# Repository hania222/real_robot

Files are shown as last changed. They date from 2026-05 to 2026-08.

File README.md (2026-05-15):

# Real Robot: Setup & Commissioning Guide
## Table of Contents

1. [SSH Connection, Repo Clone & Dependency Install](#1-ssh-connection-repo-clone--dependency-install)
2. [udev Fixed Device Names for RPLidar & ESP32](#2-udev-fixed-device-names-for-rplidar--esp32)
3. [PID Tuning & Physical Calibration](#3-pid-tuning--physical-calibration)
4. [SLAM Toolbox — Building the Map](#4-slam-toolbox--building-the-map)
5. [Nav2 — Autonomous Navigation](#5-nav2--autonomous-navigation)
---

## 1. SSH Connection, Repo Clone & Dependency Install

### 1.1 Find the Pi 5's IP address

Run this on the Pi (connected to a monitor temporarily, or check the router's DHCP table):

```bash
hostname -I
# returns something like 192.168.1.42 — note this down
```
---

### 1.2 SSH from the Windows laptop into Pi 5
Both devices must be on the same network (same Wi-Fi or router).

```powershell
# In Windows PowerShell
ssh hania@192.168.1.42
# Replace the IP with the one from step 1.1
# Default Pi username is 'hania' — change if different
# Accept the fingerprint prompt , enter ur Pi password
```

>  **Tip:** To avoid typing the password every time, set up SSH key auth: run `ssh-keygen` on Windows, then `ssh-copy-id hania@<IP>`.

---

### 1.3 Create workspace and clone the repo

All commands run on Pi 5 over SSH.

```bash
# Create workspace
mkdir -p ~/robot_ws/src
cd ~/robot_ws/src

# Clone the repo
git clone https://github.com/hania222/real_robot.git

# Verify it cloned
ls real_robot/
```

---

### 1.4 Run install_deps.sh to install all dependencies

Installs ROS 2 packages, Nav2, slam_toolbox, robot_localization, and more.

```bash
cd ~/robot_ws/src/real_robot
chmod +x install_deps.sh
./install_deps.sh
# This will sudo apt install everything — takes a few minutes
```

> **micro-ROS agent is NOT available via apt, it must be built from source.** 

micro-ROS agent must be built from source, it's not available via apt. Build it once here, then run it manually in its own terminal to verify the ESP32 is connected
and publishing before launching bringup. It's commented out in bringup.launch.py intentionally, uncomment it only after confirming everything works end-to-end.:

```bash
cd ~
git clone https://github.com/micro-ROS/micro_ros_setup.git src/micro_ros_setup
cd ~/robot_ws
colcon build --packages-select micro_ros_setup
source install/setup.bash
ros2 run micro_ros_setup create_agent_ws.sh
ros2 run micro_ros_setup build_agent.sh
source install/setup.bash
```

---

### 1.5 Build the workspace

```bash
cd ~/robot_ws
colcon build --symlink-install
source install/setup.bash

# Add to .bashrc so it auto-sources on every SSH login
echo "source ~/robot_ws/install/setup.bash" >> ~/.bashrc
source ~/.bashrc
```
>note: we will use our built .bashrc directly 
---

## 2. udev Fixed Device Names for RPLidar & ESP32

> **Why this matters:** Linux assigns `/dev/ttyUSB0` and `/dev/ttyUSB1` randomly on boot. without udev rules the launch files will connect to the wrong device. These rules pin names by USB vendor/product ID so the lidar is always `/dev/rplidar` and the ESP32 is always `/dev/esp32`.

### 2.1 Find the USB vendor and product IDs

```bash
# Plug only the RPLidar in first
lsusb
# Look for "Silicon Labs CP210x" or "Prolific" — note idVendor:idProduct
# Example: Bus 001 Device 003: ID 10c4:ea60 Silicon Labs CP210x

# Now also plug in the ESP32
lsusb
# ESP32 usually shows up as Silicon Labs CP2102 or CH340
# Note the different idVendor:idProduct for each

# Also check the serial number to distinguish two Silicon Labs devices
udevadm info /dev/ttyUSB0 | grep -E "ID_VENDOR_ID|ID_MODEL_ID|ID_SERIAL_SHORT"
udevadm info /dev/ttyUSB1 | grep -E "ID_VENDOR_ID|ID_MODEL_ID|ID_SERIAL_SHORT"
```

---

### 2.2 Create the udev rules file

```bash
sudo nano /etc/udev/rules.d/99-robot.rules
```

Paste this: replace values with what we got:

```
# RPLidar A1 (Silicon Labs CP2102 — adjust ATTRS if needed)
SUBSYSTEM=="tty", ATTRS{idVendor}=="10c4", ATTRS{idProduct}=="ea60", \
  ATTRS{serial}=="YOUR_LIDAR_SERIAL", \
  SYMLINK+="rplidar", MODE="0666"

# ESP32 (CP2102 or CH340 — adjust idVendor/idProduct)
SUBSYSTEM=="tty", ATTRS{idVendor}=="10c4", ATTRS{idProduct}=="ea60", \
  ATTRS{serial}=="YOUR_ESP32_SERIAL", \
  SYMLINK+="esp32", MODE="0666"
```

>  If both devices share the same VID:PID (both are CP2102), use the serial number field to tell them apart — that's why u ran the `ID_SERIAL_SHORT` check above.

---

### 2.3 Reload udev and verify symlinks

Unplug and replug both USB devices after reloading.

```bash
sudo udevadm control --reload-rules
sudo udevadm trigger

# Unplug both, replug both, then verify:
ls -la /dev/rplidar /dev/esp32
# Both should appear as symlinks → /dev/ttyUSBx
```

> Update `bringup.launch.py`'s `serial_port` to `/dev/rplidar` now that the symlink is stable.

---

## 3. PID Tuning & Physical Calibration

> **Before starting:** launch bringup first (`ros2 launch real_bringup bringup.launch.py`), then the joystick or step_tester in a separate terminal. PlotJuggler subscribes to `/pid_debug` to visualise target vs actual speed in real time.

---

### Step 1 — PID Tuning (KP first, then KI, then KD)

Use `step_tester.py` in linear mode + PlotJuggler `/pid_debug`.

```bash
# Terminal 1 — bringup
ros2 launch real_bringup bringup.launch.py

# Terminal 2 — step tester (3 s ON / 3 s OFF cycle)
python3 step_tester.py linear

# Terminal 3 — live publish gains without reflashing
ros2 topic pub /pid_gains std_msgs/msg/String \
  "data: 'kp_l:80.0 ki_l:5.0 kd_l:1.0 kp_r:80.0 ki_r:5.0 kd_r:1.0'"
```

**Tuning order:**
1. Set KI=0 KD=0. Raise KP until actual speed tracks target without oscillation in PlotJuggler.
2. Slowly raise KI (try 1 → 2 → 5) until the steady-state offset closes. Halve if oscillation appears.
3. Add KD (try 0.5 → 1 → 2) only if velocity still oscillates with good KP + KI. Usually not needed.

> When satisfied, write the final KP/KI/KD values back into `config.h` and reflash the ESP32 — the `/pid_gains` topic is runtime-only and resets on reboot.

---

### Step 2 — Verify wheel radius (tape measure)

Confirm `WHEEL_RADIUS = 0.065 m` in `config.h` matches the physical wheel.

1. Mark a straight line on the floor. Place the robot with the wheel edge on the line.
2. Command a known distance — e.g. run `step_tester.py linear` for exactly 3 s at 0.3 m/s → expected travel = 0.9 m.
3. Measure the actual distance traveled with a tape measure.
4. If actual ≠ expected: `new_radius = (actual / expected) × 0.065`. Update `WHEEL_RADIUS` in `config.h` and reflash.

```bash
# Check /odom reports expected distance too
ros2 topic echo /odom --once
# pose.pose.position.x should match tape measure
```

---

### Step 3 — Verify wheel base (360° spin test)

Confirm `WHEEL_BASE = 0.642 m` matches physical axle separation.

1. Put a marker (tape) under the robot centre. Run `step_tester.py angular` until the robot completes exactly one full 360° spin.
2. If the robot overshoots: increase `WHEEL_BASE`. If it undershoots: decrease it.
3. Formula: `new_base = (actual_degrees / 360) × 0.642`
4. Update `config.h` and also `ekf.yaml` if derived from the URDF joints (URDF has 0.642 m: left_drive y=0.321 + right_drive y=0.321).

```bash
# Monitor yaw angle from odometry during spin
ros2 topic echo /odom | grep -A2 "orientation"
```

---

### Step 4 — Minimum reliable speed (`MIN_LINEAR`)

Find the slowest speed at which both wheels move without stalling.

1. Command progressively slower speeds via `/pid_gains` and `step_tester.py`.
2. In PlotJuggler watch `actual_v_left` and `actual_v_right` — the minimum speed where both wheels consistently move is your `MIN_LINEAR`.
3. Update `MIN_LINEAR` in `joystick_ws_node.py` and `MIN_WHEEL_SPEED` in `config.h` to match.
4. Also set `min_vel_x` in `nav2_params.yaml` to the same number.

Current default: `MIN_LINEAR = 0.10 m/s`

---

### Step 5 — Acceleration / deceleration profile

Tune `MAX_ACCEL_PER_TICK` so the robot starts smoothly without jerking.

1. Run `step_tester.py linear` and watch the *slewed target* line (`debug_data[0]`) in PlotJuggler — it should ramp smoothly.
2. If the gearbox jolts on start: lower `MAX_ACCEL_PER_TICK` from `0.05` to `0.03` in `config.h`.
3. If the robot reaches cruising speed too slowly: raise to `0.1` or `0.2`.

Current default: `0.05 m/s per 50 ms tick = 1.0 m/s² acceleration`

```
# PlotJuggler topics to watch:
# /pid_debug → [0] slewed_left, [1] actual_left, [3] pwm_left
#               [4] slewed_right, [5] actual_right, [7] pwm_right
```

---

### Step 6 — Verify robot footprint dimensions

Tape measure the physical robot for the Nav2 footprint polygon (outermost points including caster wheels).

```yaml
# In nav2_params.yaml, update the footprint polygon:
footprint: [[-0.15, 0.32], [0.50, 0.32], [0.50, -0.32], [-0.15, -0.32]]
# Adjust X,Y values to match tape measure results (in metres)
# X = front/back from robot centre, Y = left/right from centre
```

>  From the URDF: chassis extends roughly +0.35 m to the front, −0.15 m to the rear, ±0.32 m sideways — verify against the real robot.

---

## 4. SLAM Toolbox — Building the Map

>  **TwistStamped vs Twist:** During SLAM, the joystick node publishes `TwistStamped` on `/cmd_vel_stamped` directly to the ESP32. The `twist_to_twiststamped.py` bridge converts `/cmd_vel → /cmd_vel_stamped` if using tools that publish plain Twist (like `teleop_twist_keyboard`). Make sure the bridge is running during SLAM manual driving.

### 4.1 Start bringup

```bash
# Terminal 1 (always start bringup first)
ros2 launch real_bringup bringup.launch.py

# Wait ~3 seconds, then verify TF tree:
ros2 run tf2_tools view_frames
# Should show: odom → CHASSIS → LIDAR and imu_link
# If odom→CHASSIS is missing, EKF hasn't started yet — wait and retry
```

> Uncomment the `micro_ros_agent` block in `bringup.launch.py` before running on the real robot

---

### 4.2 Launch SLAM toolbox

```bash
# Terminal 2
ros2 launch real_bringup slam.launch.py
# slam_params.yaml must set odom_frame: odom and base_frame: CHASSIS
# use_sim_time: false
```

---

### 4.3 Drive the robot to build the map

```bash
#  WebSocket joystick (Terminal 3 on Pi)
ros2 launch real_bringup joystick.launch.py
# Open the joystick HTML page in browser → connect to ws://<PI_IP>:8765
```

Drive slowly and cover all areas. Watch RViz to confirm the map is building cleanly without jumps.

---

### 4.4 View the map in RViz (Windows laptop)

Both machines must be on the same network and share the same `ROS_DOMAIN_ID`.

```powershell
# On Windows (ROS 2 must be installed) — PowerShell
set ROS_DOMAIN_ID=0
rviz2
# Add displays: Map (/map), LaserScan (/scan), TF, RobotModel
```

> Alternatively, run RViz on the Pi over SSH with X forwarding: `ssh -X hania@<PI_IP>` then `rviz2` — but this is slow over Wi-Fi.

---

### 4.5 Save the map

```bash
# While SLAM is still running — save the map
ros2 run nav2_map_server map_saver_cli \
  -f ~/robot_ws/src/real_robot/real_bringup/maps/real_map
# Creates real_map.pgm (image) and real_map.yaml (metadata)
# navigation.launch.py already points to real_map.yaml by default
```

---

## 5. Nav2 — Autonomous Navigation

>  **Twist vs TwistStamped for Nav2:** Nav2's `controller_server` publishes plain `Twist` on `/cmd_vel` by default. The ESP32 subscribes to `TwistStamped` on `/cmd_vel_stamped`. we must either:
> - **(a)** Run the `twist_to_twiststamped.py` bridge alongside Nav2, or
> - **(b)** Configure Nav2 to publish TwistStamped directly: set `enable_stamped_cmd_vel: true` in `nav2_params.yaml` (available in Nav2 Jazzy/Iron+).
>
> Option (b) is cleaner — no extra node needed.

### 5.1 Configure nav2_params.yaml

```yaml
# Under controller_server:
enable_stamped_cmd_vel: true   # publishes TwistStamped on /cmd_vel_stamped

# Under local_costmap and global_costmap:
robot_base_frame: CHASSIS       # must match EKF base_link_frame

# Under DWB or MPPI controller:
min_vel_x: 0.10                 # match MIN_LINEAR from step 3.4
max_vel_x: 0.70                 # match MAX_LINEAR (70% of rated 1.2 m/s)
max_vel_theta: 1.5              # match MAX_ANGULAR

# Footprint (from step 3.6 tape measure)
footprint: "[[-0.15, 0.32], [0.50, 0.32], [0.50, -0.32], [-0.15, -0.32]]"
```

---

### 5.2 Configure amcl_params.yaml

```yaml
base_frame_id: CHASSIS
odom_frame_id: odom
scan_topic:    /scan
laser_model_type: likelihood_field
use_sim_time: false

# Particle filter sizing (start broad, tighten once map is good)
min_particles: 500
max_particles: 2000
```

---

### 5.3 Launch bringup + navigation

```bash
# Terminal 1
ros2 launch real_bringup bringup.launch.py

# Terminal 2 — waits 5 s automatically via TimerAction
ros2 launch real_bringup navigation.launch.py

# Optionally pass a different map
ros2 launch real_bringup navigation.launch.py \
  map:=/path/to/another_map.yaml
```

> The lifecycle manager is delayed 5 s in `navigation.launch.py` to wait for bringup's TF tree to be available. If Nav2 reports "map→odom TF not available", bringup hasn't finished — increase the delay or wait before launching navigation.

---

### 5.4 Set initial pose in RViz and test navigation

1. In RViz, click **2D Pose Estimate** and click on the map at the robot's approximate location, dragging to set orientation.
2. Watch the particle cloud (AMCL) in RViz converge around the robot as it moves.
3. Click **Nav2 Goal** (or **2D Nav Goal**) and click a destination on the map.
4. Monitor `/cmd_vel_stamped` to confirm Nav2 is sending commands to the ESP32.

```bash
# Confirm Nav2 is sending velocity commands
ros2 topic echo /cmd_vel_stamped

# Check AMCL particle convergence
ros2 topic echo /amcl_pose
```

---

### 5.5 Troubleshooting

| Symptom | Likely cause | Fix |
|---|---|---|
| Robot doesn't move at all | micro_ros_agent not running or ESP32 not connected | Uncomment `micro_ros_agent` in `bringup.launch.py`, check `/dev/esp32` symlink |
| TF tree missing odom→CHASSIS | EKF not publishing — no `/odom` or `/imu/data` from ESP32 | Check `ros2 topic hz /odom` and `ros2 topic hz /imu/data` |
| SLAM map has jumps/tears | Driving too fast, or odometry error accumulation | Drive slower, recheck wheel radius and wheel base calibration |
| Nav2 not sending /cmd_vel_stamped | `enable_stamped_cmd_vel` not set; bridge not running | Add `enable_stamped_cmd_vel: true` to `nav2_params.yaml` or run `twist_to_twiststamped.py` bridge |
| AMCL particles scattered all over | Bad initial pose estimate or map doesn't match environment | Re-set 2D Pose Estimate in RViz; remap if environment changed significantly |
| Robot hits obstacles in Nav2 | Footprint too small in `nav2_params.yaml` | Update footprint polygon from tape measure (step 3.6) with extra margin |

---

## Quick Reference

| Item | Value |
|---|---|
| Workspace | `~/robot_ws` |
| Package | `real_bringup` |
| Map save path | `real_bringup/maps/real_map` |
| Lidar device | `/dev/rplidar` |
| ESP32 device | `/dev/esp32` |
| ROS 2 distro | Jazzy |
| URDF base frame | `CHASSIS` |
| Odom frame | `odom` |
| Wheel radius | `0.065 m` |
| Wheel base | `0.642 m` |
| Min linear speed | `0.10 m/s` |

---

**Repo:** [github.com/hania222/real_robot](https://github.com/hania222/real_robot) · Workspace: `~/robot_ws` · ROS 2 Jazzy · micro-ROS on ESP32

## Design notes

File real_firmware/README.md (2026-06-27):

# Carriage Subsystem — Wiring Reference

## Active-LOW wiring (negative pins → ESP32 GPIOs, positive pins → 3.3V)
ESP32 is 3.3V logic — add a 1kΩ resistor in series on each signal line (PUL, DIR, ENA).

| From | To | Note |
|---|---|---|
| ESP32 GPIO 18 | 1kΩ resistor → TB6600 Rot PUL− | Rotation step pulse |
| ESP32 GPIO 19 | 1kΩ resistor → TB6600 Rot DIR− | Rotation direction |
| ESP32 GPIO 21 | 1kΩ resistor → TB6600 Rot ENA− | Rotation enable (LOW = enabled) |
| ESP32 GPIO 22 | 1kΩ resistor → TB6600 Ext1 PUL− | Extension step pulse (both drivers) |
| ESP32 GPIO 22 | 1kΩ resistor → TB6600 Ext2 PUL− | Same GPIO wired to both |
| ESP32 GPIO 23 | 1kΩ resistor → TB6600 Ext1 DIR− | Extension direction (both drivers) |
| ESP32 GPIO 23 | 1kΩ resistor → TB6600 Ext2 DIR− | Same GPIO wired to both |
| ESP32 GPIO 25 | 1kΩ resistor → TB6600 Ext1 ENA− | Extension driver 1 enable |
| ESP32 GPIO 26 | 1kΩ resistor → TB6600 Ext2 ENA− | Extension driver 2 enable |
| ESP32 3.3V | TB6600 Rot PUL+ |  |
| ESP32 3.3V | TB6600 Rot DIR+ | |
| ESP32 3.3V | TB6600 Rot ENA+ | |
| ESP32 3.3V | TB6600 Ext1 PUL+ | |
| ESP32 3.3V | TB6600 Ext1 DIR+ | |
| ESP32 3.3V | TB6600 Ext1 ENA+ | |
| ESP32 3.3V | TB6600 Ext2 PUL+ | |
| ESP32 3.3V | TB6600 Ext2 DIR+ | |
| ESP32 3.3V | TB6600 Ext2 ENA+ | |
| ESP32 GND | TB6600 Rot GND (signal) |  |
| ESP32 GND | TB6600 Ext1 GND (signal) | |
| ESP32 GND | TB6600 Ext2 GND (signal) | |
| ESP32 GPIO 32 | Arm home switch leg A | LOW = triggered |
| ESP32 GPIO 13 | Arm end switch leg A | |
| ESP32 GPIO 33 | Rotation home switch leg A | LOW = triggered |
| ESP32 GND | All switch leg B | |
| ESP32 GPIO 27 | Servo left signal | SG90 signal wire |
| ESP32 GPIO 14 | Servo right signal | SG90 signal wire |
| External 5V rail | Both SG90 red wire (VCC) | Do NOT power servos from ESP32 5V pin |
| External 5V GND | Both SG90 brown wire (GND) | |
| External 5V GND | ESP32 GND | Common ground between servo rail and ESP32 |
| 24V PSU positive | TB6600 Rot VCC | Motor power |
| 24V PSU positive | TB6600 Ext1 VCC | |
| 24V PSU positive | TB6600 Ext2 VCC | |
| 24V PSU negative | TB6600 Rot GND (power) | |
| 24V PSU negative | TB6600 Ext1 GND (power) | |
| 24V PSU negative | TB6600 Ext2 GND (power) | |
| 24V PSU negative | ESP32 GND | Star ground — tie all GNDs together |
| TB6600 Rot A+ | Rotation NEMA23 coil A+ | |
| TB6600 Rot A− | Rotation NEMA23 coil A− | |
| TB6600 Rot B+ | Rotation NEMA23 coil B+ | |
| TB6600 Rot B− | Rotation NEMA23 coil B− | |
| TB6600 Ext1 A+ | Extension NEMA17 motor 1 coil A+ | |
| TB6600 Ext1 A− | Extension NEMA17 motor 1 coil A− | |
| TB6600 Ext1 B+ | Extension NEMA17 motor 1 coil B+ | |
| TB6600 Ext1 B− | Extension NEMA17 motor 1 coil B− | |
| TB6600 Ext2 A+ | Extension NEMA17 motor 2 coil A+ | |
| TB6600 Ext2 A− | Extension NEMA17 motor 2 coil A− | |
| TB6600 Ext2 B+ | Extension NEMA17 motor 2 coil B+ | |
| TB6600 Ext2 B− | Extension NEMA17 motor 2 coil B− | |

Firmware: `enable_driver()` writes LOW, `disable_driver()` writes HIGH.
`DRIVER_ENABLE_LEVEL LOW`, `DRIVER_DISABLE_LEVEL HIGH` in config.

---

## Active-HIGH wiring (positive pins → ESP32 GPIOs, negative pins → GND)
Simpler for 3.3V ESP32 — no resistors needed because GND reference is solid.
The optocoupler sees the full 3.3V swing directly

| From | To | Note |
|---|---|---|
| ESP32 GPIO 18 | TB6600 Rot PUL+ | Rotation step pulse |
| ESP32 GPIO 19 | TB6600 Rot DIR+ | Rotation direction |
| ESP32 GPIO 21 | TB6600 Rot ENA+ | Rotation enable (HIGH = enabled) |
| ESP32 GPIO 22 | TB6600 Ext1 PUL+ | Extension step pulse (both drivers) |
| ESP32 GPIO 22 | TB6600 Ext2 PUL+ | Same GPIO wired to both |
| ESP32 GPIO 23 | TB6600 Ext1 DIR+ | Extension direction (both drivers) |
| ESP32 GPIO 23 | TB6600 Ext2 DIR+ | Same GPIO wired to both |
| ESP32 GPIO 25 | TB6600 Ext1 ENA+ | Extension driver 1 enable |
| ESP32 GPIO 26 | TB6600 Ext2 ENA+ | Extension driver 2 enable |
| ESP32 GND | TB6600 Rot PUL− | -ve side of optocoupler tied to GND |
| ESP32 GND | TB6600 Rot DIR− | |
| ESP32 GND | TB6600 Rot ENA− | |
| ESP32 GND | TB6600 Ext1 PUL− | |
| ESP32 GND | TB6600 Ext1 DIR− | |
| ESP32 GND | TB6600 Ext1 ENA− | |
| ESP32 GND | TB6600 Ext2 PUL− | |
| ESP32 GND | TB6600 Ext2 DIR− | |
| ESP32 GND | TB6600 Ext2 ENA− | |
| ESP32 GND | TB6600 Rot GND (signal) | Common ground |
| ESP32 GND | TB6600 Ext1 GND (signal) | |
| ESP32 GND | TB6600 Ext2 GND (signal) | |
| ESP32 GPIO 32 | Arm home switch leg A | INPUT_PULLUP, LOW = triggered |
| ESP32 GPIO 13 | Arm end switch leg A | INPUT_PULLUP, LOW = triggered  |
| ESP32 GPIO 33 | Rotation home switch leg A | INPUT_PULLUP, LOW = triggered |
| ESP32 GND | All switch leg B | |
| ESP32 GPIO 27 | Servo left signal | SG90 signal wire |
| ESP32 GPIO 14 | Servo right signal | SG90 signal wire |
| External 5V rail | Both SG90 red wire (VCC) |  |
| External 5V GND | Both SG90 brown wire (GND) | |
| External 5V GND | ESP32 GND | Common ground between servo rail and ESP32 |
| 24V PSU positive | TB6600 Rot VCC | Motor power |
| 24V PSU positive | TB6600 Ext1 VCC | |
| 24V PSU positive | TB6600 Ext2 VCC | |
| 24V PSU negative | TB6600 Rot GND (power) | |
| 24V PSU negative | TB6600 Ext1 GND (power) | |
| 24V PSU negative | TB6600 Ext2 GND (power) | |
| 24V PSU negative | ESP32 GND | all GNDs together |
| TB6600 Rot A+ | Rotation NEMA23 coil A+ | |
| TB6600 Rot A− | Rotation NEMA23 coil A− | |
| TB6600 Rot B+ | Rotation NEMA23 coil B+ | |
| TB6600 Rot B− | Rotation NEMA23 coil B− | |
| TB6600 Ext1 A+ | Extension NEMA17 motor 1 coil A+ | |
| TB6600 Ext1 A− | Extension NEMA17 motor 1 coil A− | |
| TB6600 Ext1 B+ | Extension NEMA17 motor 1 coil B+ | |
| TB6600 Ext1 B− | Extension NEMA17 motor 1 coil B− | |
| TB6600 Ext2 A+ | Extension NEMA17 motor 2 coil A+ | |
| TB6600 Ext2 A− | Extension NEMA17 motor 2 coil A− | |
| TB6600 Ext2 B+ | Extension NEMA17 motor 2 coil B+ | |
| TB6600 Ext2 B− | Extension NEMA17 motor 2 coil B− | |

Firmware: `enable_driver()` writes HIGH, `disable_driver()` writes LOW.
`DRIVER_ENABLE_LEVEL HIGH`, `DRIVER_DISABLE_LEVEL LOW` in config.

---

# Lift Subsystem — Wiring Reference
| From | To |
|---|---|
| Arduino D4 | TB6600 Driver 1 PUL− |
| Arduino D4 | TB6600 Driver 2 PUL− |
| Arduino D5 | TB6600 Driver 1 DIR− |
| Arduino D5 | TB6600 Driver 2 DIR− |
| Arduino D6 | TB6600 Driver 1 ENA− |
| Arduino D7 | TB6600 Driver 2 ENA− |
| Arduino D8 | Bottom limit switch leg A |
| Arduino D9 | Top limit switch leg A |
| Arduino 5V | TB6600 Driver 1 PUL+ |
| Arduino 5V | TB6600 Driver 1 DIR+ |
| Arduino 5V | TB6600 Driver 1 ENA+ |
| Arduino 5V | TB6600 Driver 2 PUL+ |
| Arduino 5V | TB6600 Driver 2 DIR+ |
| Arduino 5V | TB6600 Driver 2 ENA+ |
| Arduino GND | TB6600 Driver 1 GND (signal) |
| Arduino GND | TB6600 Driver 2 GND (signal) |
| Arduino GND | Bottom limit switch leg B |
| Arduino GND | Top limit switch leg B |
| Arduino GND | 24V PSU negative |
| 24V PSU positive | TB6600 Driver 1 VCC |
| 24V PSU positive | TB6600 Driver 2 VCC |
| 24V PSU negative | TB6600 Driver 1 GND (power) |
| 24V PSU negative | TB6600 Driver 2 GND (power) |
| TB6600 Driver 1 A+ | Motor 1 coil A+ |
| TB6600 Driver 1 A− | Motor 1 coil A− |
| TB6600 Driver 1 B+ | Motor 1 coil B+ |
| TB6600 Driver 1 B− | Motor 1 coil B− |
| TB6600 Driver 2 A+ | Motor 2 coil A+ |
| TB6600 Driver 2 A− | Motor 2 coil A− |
| TB6600 Driver 2 B+ | Motor 2 coil B+ |
| TB6600 Driver 2 B− | Motor 2 coil B− |

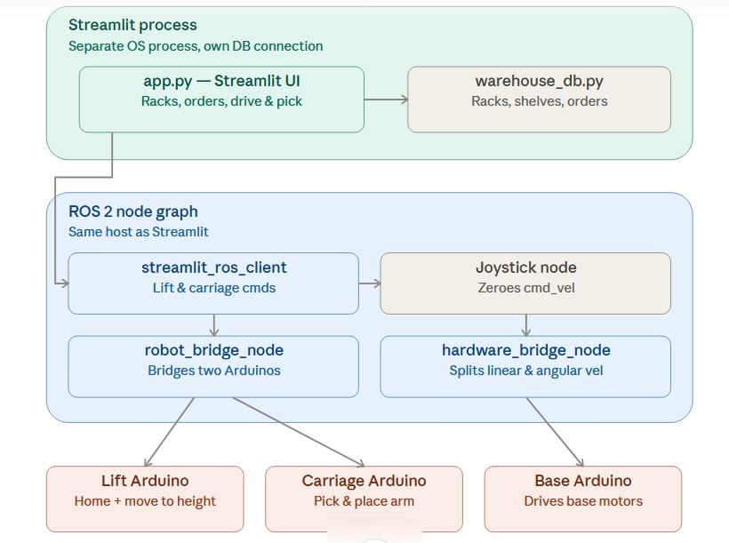
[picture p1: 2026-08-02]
management_system/sysetm_architecture.jpeg

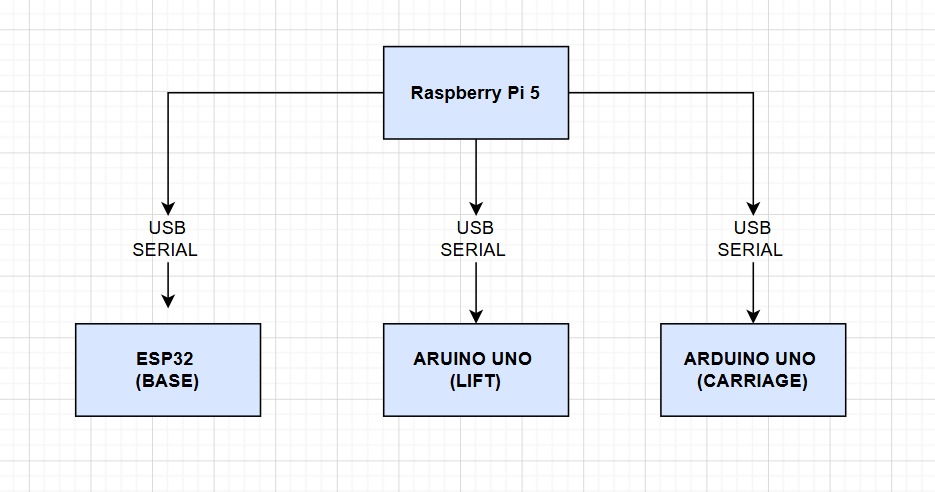
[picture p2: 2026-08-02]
management_system/system.jpeg

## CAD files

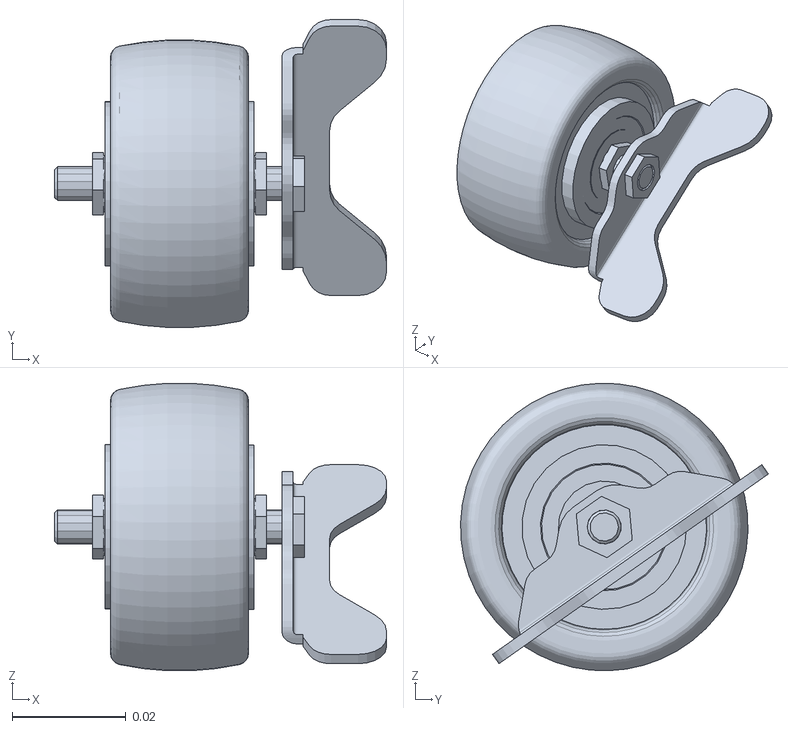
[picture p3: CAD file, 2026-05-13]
real_description/meshes/RL_swivel.STL
0.0584 x 0.0542 x 0.0506

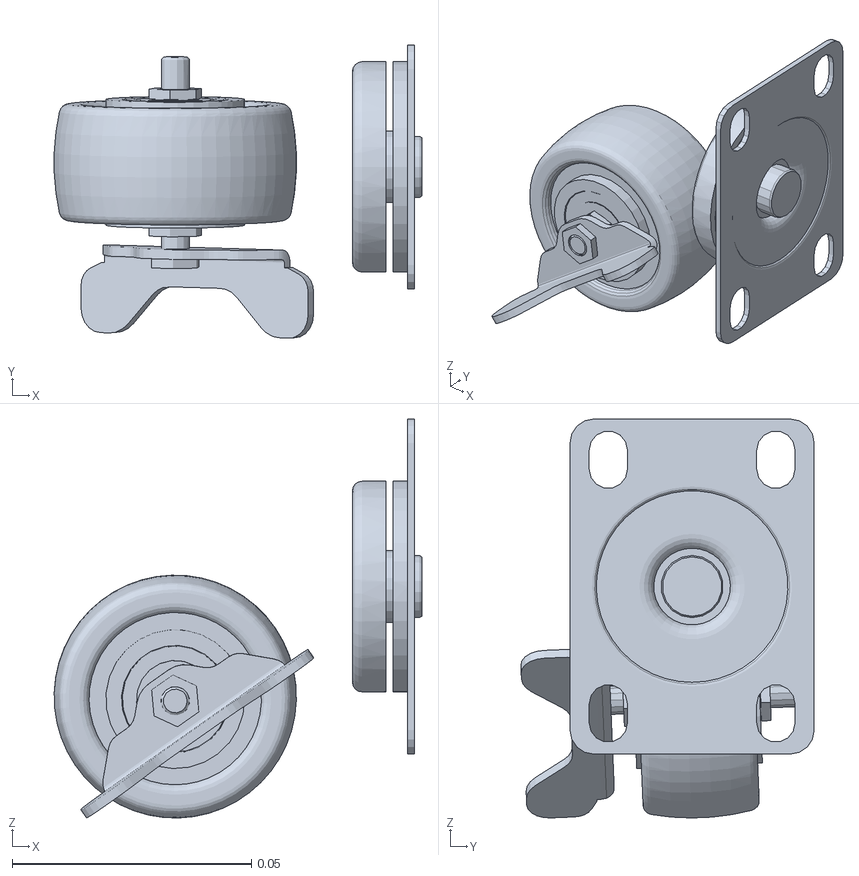
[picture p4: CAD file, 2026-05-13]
real_description/meshes/FR_swivel.STL
0.0768 x 0.0613 x 0.0833

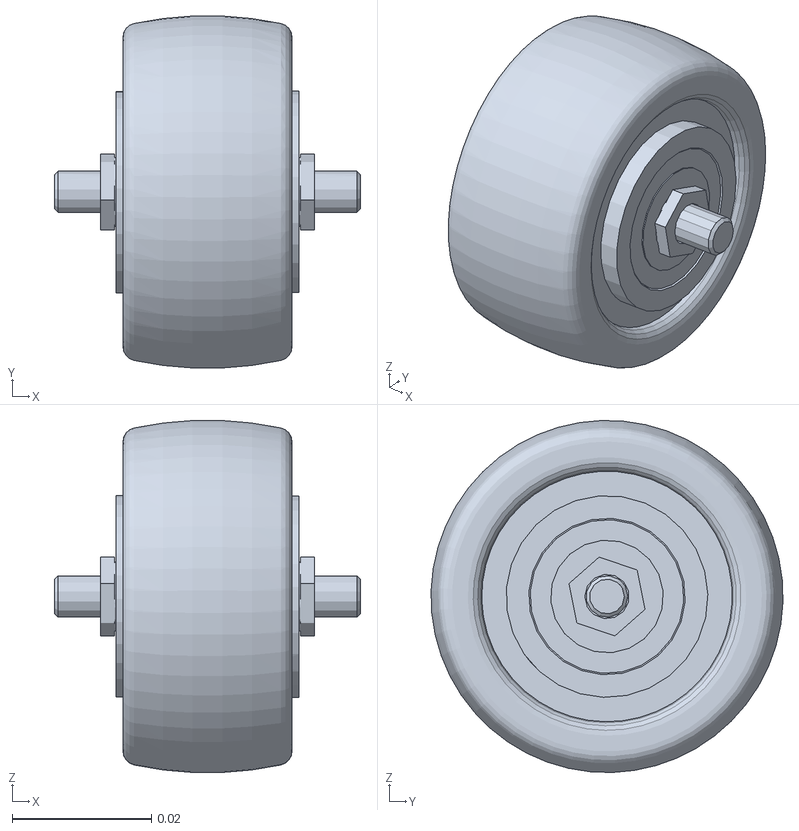
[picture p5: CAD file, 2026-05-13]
real_description/meshes/RR_roll.STL
0.044 x 0.0506 x 0.0506

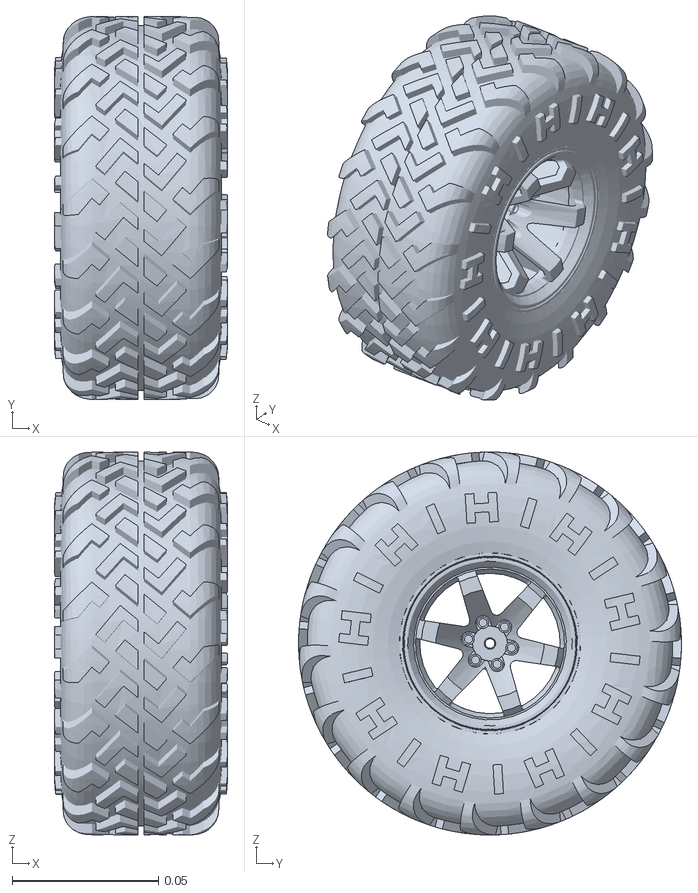
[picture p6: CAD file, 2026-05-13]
real_description/meshes/LEFT_drive.STL
0.0592 x 0.131 x 0.131

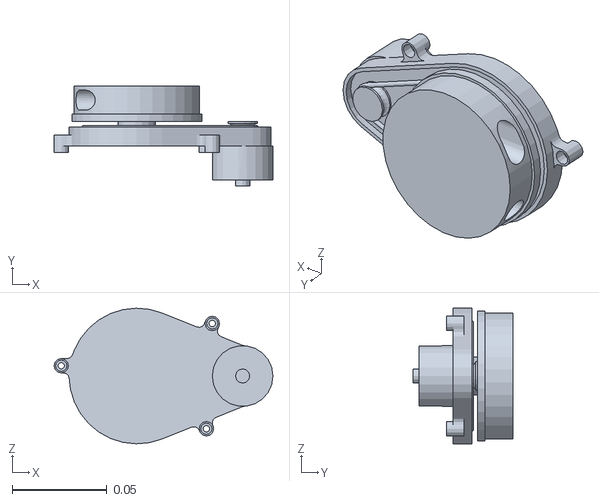
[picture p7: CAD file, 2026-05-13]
real_description/meshes/LIDAR.STL
0.115 x 0.0525 x 0.0715

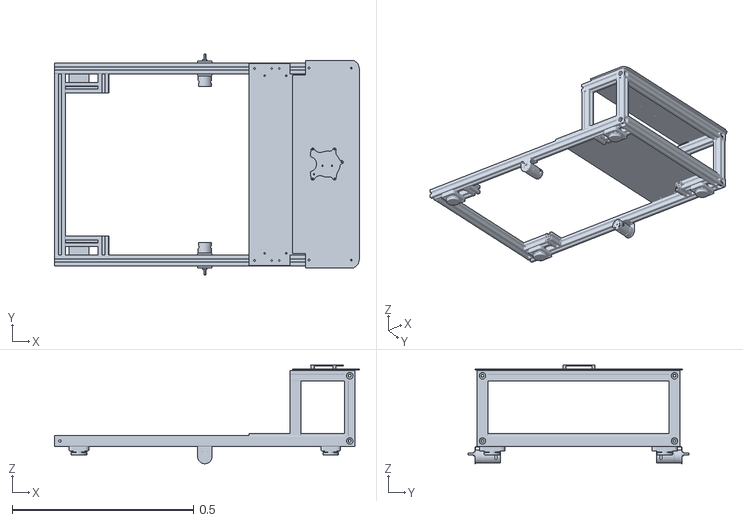
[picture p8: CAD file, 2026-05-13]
real_description/meshes/CHASSIS.STL
0.842 x 0.61 x 0.272

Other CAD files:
real_description/meshes/FL_roll.STL
real_description/meshes/RL_roll.STL
real_description/meshes/RIGHT_drive.STL
real_description/meshes/RR_swivel.STL
real_description/meshes/FR_roll.STL
real_description/meshes/FL_swivel.STL

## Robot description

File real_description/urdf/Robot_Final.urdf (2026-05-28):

<?xml version="1.0" encoding="utf-8"?>
<robot name="Robot_Final">

  <link name="CHASSIS">
    <inertial>
      <origin xyz="0.148972616629833 8.59131719513906E-05 0.037381334125696" rpy="0 0 0" />
      <mass value="5.23357376650206" />
      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
    </inertial>
    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
  </link>
  
 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
  <link name="FL_swivel">
    <inertial>
      <origin xyz="-0.0225271927865878 8.25455349966892E-06 -0.0150973351650807" rpy="0 0 0" />
      <mass value="0.080127289502846" />
      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
    </inertial>
    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
  </link>
  <joint name="fl_swivel" type="continuous">
    <origin xyz="0.34749994000006 0.238309957246437 -0.0550828883294601" rpy="1.5707963267949 -1.5707963267949 0" />
    <parent link="CHASSIS" />
    <child link="FL_swivel" />
    <axis xyz="-1 0 0" />
  </joint>

  <link name="FL_roll">
    <inertial>
      <origin xyz="0 1.38777878078145E-17 0" rpy="0 0 0" />
      <mass value="0.0472944068607781" />
      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
    </inertial>
    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
  </link>
  <joint name="fl_roll" type="continuous">
    <origin xyz="-0.0369999999999996 0.000959824507810431 -0.0229799638144681" rpy="0 0.0417436225359922 -1.57079632679489" />
    <parent link="FL_swivel" />
    <child link="FL_roll" />
    <axis xyz="1 0 0" />
  </joint>

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
  <link name="FR_swivel">
    <inertial>
      <origin xyz="-0.0355271927865884 8.25455350048077E-06 -0.0150973351650687" rpy="0 0 0" />
      <mass value="0.0801272895028461" />
      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
    </inertial>
    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
  </link>
  <joint name="fr_swivel" type="continuous">
    <origin xyz="0.347499940000059 -0.238309957200129 -0.0420828883294584" rpy="1.5707963267949 -1.5707963267949 0" />
    <parent link="CHASSIS" />
    <child link="FR_swivel" />
    <axis xyz="1 0 0" />
  </joint>

  <link name="FR_roll">
    <inertial>
      <origin xyz="-1.38777878078145E-17 0 0" rpy="0 0 0" />
      <mass value="0.0472944068607781" />
      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
    </inertial>
    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
  </link>
  <joint name="fr_roll" type="continuous">
    <origin xyz="-0.0500000000000001 0.000959824507811236 -0.0229799638144561" rpy="3.14159265358979 -0.0417436225359922 1.5707963267949" />
    <parent link="FR_swivel" />
    <child link="FR_roll" />
    <axis xyz="1 0 0" />
  </joint>

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
  <link name="RL_swivel">
    <inertial>
      <origin xyz="0.695215418771256 0.00502743200085908 0.0320864502764693" rpy="0 0 0" />
      <mass value="0.0606861535098016" />
      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
    </inertial>
    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
  </link>
  <joint name="rl_swivel" type="continuous">
    <origin xyz="0.348459764507871 0.215329993431968 -0.0920828883294597" rpy="1.5707963267949 0 -3.0998490310538" />
    <parent link="CHASSIS" />
    <child link="RL_swivel" />
    <axis xyz="0 1 0" />
  </joint>

  <link name="RL_roll">
    <inertial>
      <origin xyz="0 1.38777878078145E-17 0" rpy="0 0 0" />
      <mass value="0.0472944068607779" />
      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
    </inertial>
    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
  </link>
  <joint name="rl_roll" type="continuous">
    <origin xyz="0.694394438846155 0 0.0290033877282606" rpy="3.14159265358979 0 3.14159265358979" />
    <parent link="RL_swivel" />
    <child link="RL_roll" />
    <axis xyz="1 0 0" />
  </joint>

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
  <link name="RR_swivel">
    <inertial>
      <origin xyz="-0.035527192786591 -8.25455350095261E-06 0.0150973351650685" rpy="0 0 0" />
      <mass value="0.080127289502846" />
      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
    </inertial>
    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
  </link>
  <joint name="rr_swivel" type="continuous">
    <origin xyz="-0.347499940000062 -0.238309957200129 -0.0420828883294612" rpy="1.5707963267949 -1.5707963267949 0" />
    <parent link="CHASSIS" />
    <child link="RR_swivel" />
    <axis xyz="1 0 0" />
  </joint>

  <link name="RR_roll">
    <inertial>
      <origin xyz="1.11022302462516E-16 0 -1.11022302462516E-16" rpy="0 0 0" />
      <mass value="0.047294406860778" />
      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
    </inertial>
    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
  </link>
  <joint name="rr_roll" type="continuous">
    <origin xyz="-0.0500000000000028 -0.000959824507811624 0.0229799638144559" rpy="3.14159265358978 -0.0417436225359922 1.57079632679489" />
    <parent link="RR_swivel" />
    <child link="RR_roll" />
    <axis xyz="-1 0 0" />
  </joint>

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
  <link name="LEFT_drive">
    <inertial>
      <origin xyz="-0.000435316178176041 1.43219237733194E-07 7.15469608836283E-07" rpy="0 0 0" />
      <mass value="0.172871365054941" />
      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
    </inertial>
    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
  </link>
  <joint name="left_drive" type="continuous">
    <origin xyz="0 0.32099994000006 -0.0519998800001306" rpy="1.5707963267949 0 1.5707963267949" />
    <parent link="CHASSIS" />
    <child link="LEFT_drive" />
    <axis xyz="1 0 0" />
  </joint>

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
  <link name="RIGHT_drive">
    <inertial>
      <origin xyz="-0.000435317384219203 3.49623845763425E-07 6.40158243581102E-07" rpy="0 0 0" />
      <mass value="0.172871342384214" />
      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
    </inertial>
    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
  </link>
  <joint name="right_drive" type="continuous">
    <origin xyz="0 -0.320999940000059 -0.0519998800001246" rpy="1.5707963267949 0 -1.5707963267949" />
    <parent link="CHASSIS" />
    <child link="RIGHT_drive" />
    <axis xyz="1 0 0" />
  </joint>

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
  <link name="LIDAR">
    <inertial>
      <origin xyz="0.0124301051678767 -0.00143154992810615 -0.000239815633560569" rpy="0 0 0" />
      <mass value="0.11668205406855" />
      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
    </inertial>
    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
  </link>
  <joint name="lidar" type="fixed">
    <origin xyz="0.337928211604104 0.0011642377654919 0.220978892743802" rpy="1.5707963267949 0 3.14159265358979" />
    <parent link="CHASSIS" />
    <child link="LIDAR" />
    <axis xyz="0 0 0" />
  </joint>

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
  <link name="imu_link">
    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
    <inertial>
      <mass value="0.01"/>
      <origin xyz="0 0 0" rpy="0 0 0"/>
      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
    </inertial>
  </link>
  <joint name="imu_joint" type="fixed">
    <parent link="CHASSIS"/>
    <child link="imu_link"/>
    <origin xyz="0.0 0.0 0.05" rpy="0 0 0"/>
  </joint>

</robot>

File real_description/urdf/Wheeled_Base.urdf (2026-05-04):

<?xml version="1.0" encoding="utf-8"?>
<robot name="Wheeled_Base">

  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
  <link name="CHASSIS">
    <inertial>
      <origin xyz="0.141596575317463 3.06351797598192E-05 0.0368731174163016" rpy="0 0 0"/>
      <mass value="3.85214064507162"/>
      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
    </inertial>
    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
  </link>

  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
  <link name="LEFT_WHEEL">
    <inertial>
      <origin xyz="7.15469609002817E-07 -0.000435316178176055 1.43219237691561E-07" rpy="0 0 0"/>
      <mass value="0.172871365054941"/>
      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
    </inertial>
    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
  </link>

  <joint name="left_wheel" type="continuous">
    <origin xyz="0 0.320999820000179 -0.0509998800001172" rpy="0 0 0"/>
    <parent link="CHASSIS"/>
    <child link="LEFT_WHEEL"/>
    <axis xyz="0 1 0"/>
    <dynamics damping="0.05" friction="0.2"/>
  </joint>

  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
  <link name="RIGHT_WHEEL">
    <inertial>
      <origin xyz="-6.4057294135722E-07 -0.000435317987241501 -3.49392368793888E-07" rpy="0 0 0"/>
      <mass value="0.172871331048852"/>
      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
    </inertial>
    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
  </link>

  <joint name="right_wheel" type="continuous">
    <origin xyz="0 -0.32100005999994 -0.0509998800001111" rpy="3.14159265358979 0 0"/>
    <parent link="CHASSIS"/>
    <child link="RIGHT_WHEEL"/>
    <axis xyz="0 1 0"/>
    <dynamics damping="0.05" friction="0.2"/>
  </joint>

  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
  <link name="FRONT_SWIVEL">
    <inertial>
      <origin xyz="-0.0013624425329018 -0.00374273524947871 -0.00167971374459603" rpy="0 0 0"/>
      <mass value="0.0328328826420678"/>
      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
    </inertial>
    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
  </link>

  <joint name="front_swivel" type="continuous">
    <origin xyz="0.399999940000059 0 -0.0540828883294461" rpy="0 0 0"/>
    <parent link="CHASSIS"/>
    <child link="FRONT_SWIVEL"/>
    <axis xyz="0 0 1"/>
    <dynamics damping="0.005" friction="0.02"/>
  </joint>

  <link name="FRONT_ROLLING">
    <inertial>
      <origin xyz="0 0 -1.73472347597681E-17" rpy="0 0 0"/>
      <mass value="0.0472944068607781"/>
      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
    </inertial>
    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
  </link>

  <joint name="front_rolling" type="continuous">
    <origin xyz="0.000959824507811111 -0.0229799638144669 -0.037" rpy="-1.5707963267949 0 -1.5290527042589"/>
    <parent link="FRONT_SWIVEL"/>
    <child link="FRONT_ROLLING"/>
    <axis xyz="0 0 1"/>
    <dynamics damping="0.01" friction="0.05"/>
  </joint>

  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
  <link name="REAR_SWIVELING">
    <inertial>
      <origin xyz="-0.00136244253290196 -0.00374273524947866 -0.00167971374459558" rpy="0 0 0"/>
      <mass value="0.0328328826420671"/>
      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
    </inertial>
    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
  </link>

  <joint name="rear_swiveling" type="continuous">
    <origin xyz="-0.400000059999942 0 -0.0540828883294474" rpy="0 0 0"/>
    <parent link="CHASSIS"/>
    <child link="REAR_SWIVELING"/>
    <axis xyz="0 0 1"/>
    <dynamics damping="0.005" friction="0.02"/>
  </joint>

  <link name="REAR_ROLLING">
    <inertial>
      <origin xyz="1.11022302462516E-16 -1.38777878078145E-17 0" rpy="0 0 0"/>
      <mass value="0.047294406860778"/>
      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
    </inertial>
    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
  </link>

  <joint name="rear_rolling" type="continuous">
    <origin xyz="0.000959824507811069 -0.0229799638144668 -0.037" rpy="1.5707963267949 0 3.14159265358979"/>
    <parent link="REAR_SWIVELING"/>
    <child link="REAR_ROLLING"/>
    <axis xyz="0.999128861498558 0 -0.041731500339619"/>
    <dynamics damping="0.01" friction="0.05"/>
  </joint>




  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
  <link name="lidar_link">
    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
    <inertial>
      <mass value="0.170"/>
      <origin xyz="0 0 0" rpy="0 0 0"/>
      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
    </inertial>
  </link>

  <joint name="lidar_joint" type="fixed">
    <parent link="CHASSIS"/>
    <child link="lidar_link"/>
    <origin xyz="-0.32 0.0 0.055" rpy="0 0 0"/>
  </joint>

  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
  <link name="imu_link">
    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
    <inertial>
      <mass value="0.01"/>
      <origin xyz="0 0 0" rpy="0 0 0"/>
      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
    </inertial>
  </link>

  <joint name="imu_joint" type="fixed">
    <parent link="CHASSIS"/>
    <child link="imu_link"/>
    <origin xyz="0.0 0.0 0.05" rpy="0 0 0"/>
  </joint>
</robot>

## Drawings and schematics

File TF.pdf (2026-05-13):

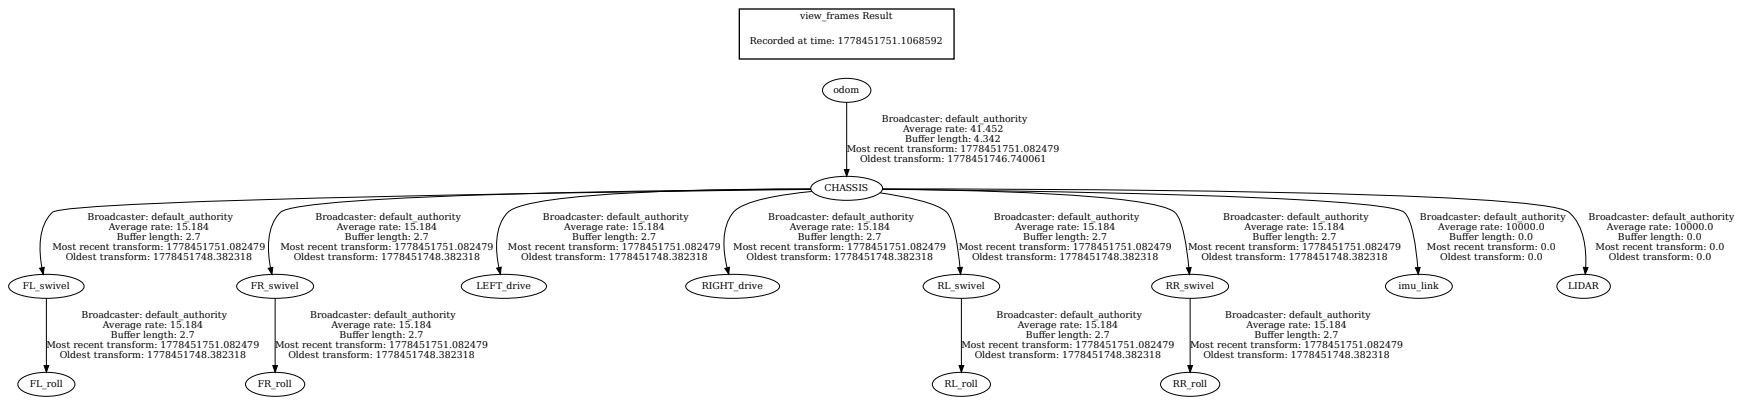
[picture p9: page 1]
view_frames Result; odom; CHASSIS; Broadcaster: default_authority Average rate: 41.452 Buffer length: 4.342; FL_swivel; Broadcaster: default_authority Average rate: 15.184 Buffer length: 2.7; FR_swivel; LEFT_drive; RIGHT_drive; RL_swivel; RR_swivel; imu_link; LIDAR; FL_roll; FR_roll; RL_roll; RR_roll

Recorded at time: 1778451751.1068592

Most recent transform: 1778451751.082479
Oldest transform: 1778451746.740061

Broadcaster: default_authority
Average rate: 10000.0
Buffer length: 0.0
Most recent transform: 0.0
Oldest transform: 0.0

Oldest transform: 1778451748.382318

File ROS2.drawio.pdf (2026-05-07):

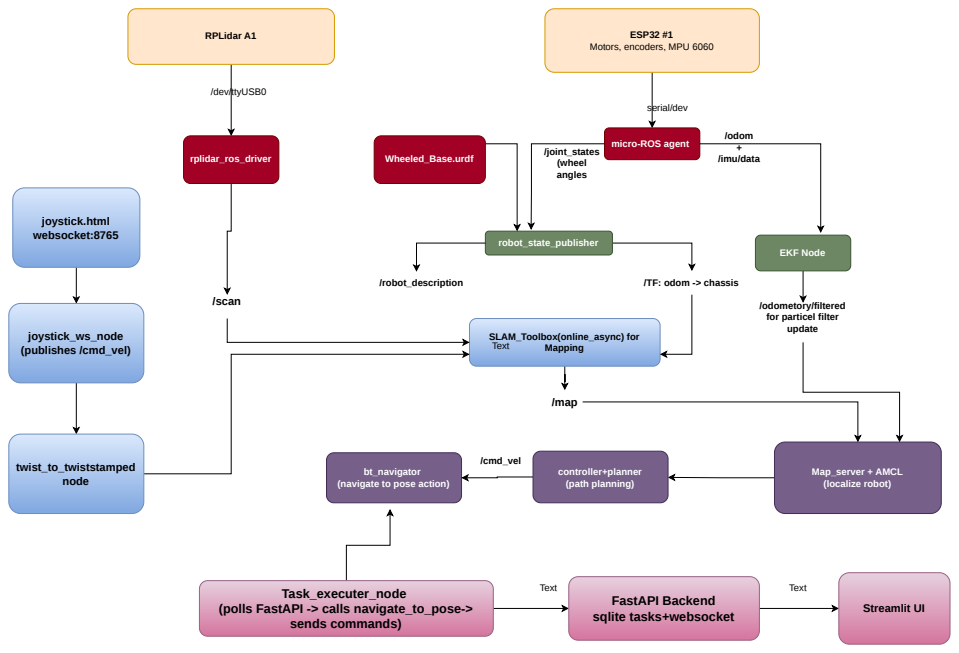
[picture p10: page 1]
serial/dev; RPLidar A1; rplidar_ros_driver; /dev/ttyUSB0; robot_state_publisher; EKF Node; /joint_states (wheel angles; Wheeled_Base.urdf; /odom + /imu/data; Map_server + AMCL (localize robot); SLAM_Toolbox(online_async) for Mapping; controller+planner (path planning); /robot_description; /TF: odom -> chassis; /scan; /odometory/filtered; /map; /cmd_vel; joystick.html websocket:8765; joystick_ws_node (publishes /cmd_vel); twist_to_twiststamped node; Task_executer_node; sends commands)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

ESP32 #1 Motors, encoders, MPU 6060

micro-ROS agent

for particel filter
update

bt_navigator
(navigate to pose action)

(polls FastAPI -> calls navigate_to_pose->

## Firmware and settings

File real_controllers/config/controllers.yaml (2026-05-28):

controller_manager:
  ros__parameters:
    update_rate: 50  # matches config.h CONTROL_LOOP_HZ

    diff_drive_controller:
      type: diff_drive_controller/DiffDriveController


diff_drive_controller:
  ros__parameters:
    left_wheel_names:  ['left_drive']
    right_wheel_names: ['right_drive']

    wheel_separation: 0.642      # matches your URDF / config.h WHEEL_BASE
    wheel_radius:     0.065      # matches your config.h WHEEL_RADIUS

    use_stamped_vel: false        
    odom_frame_id:   odom
    base_frame_id:   CHASSIS

    publish_rate: 50.0

    # Velocity limits matching  existing nav2_params.yaml
    linear.x.max_velocity:   0.70
    linear.x.min_velocity:  -0.70
    angular.z.max_velocity:  1.5
    angular.z.min_velocity: -1.5

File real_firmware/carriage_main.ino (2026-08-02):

// carriage_main_Final.ino
//
// ═══════════════════════════════════════════════════════════════════════════════
// HARDWARE OVERVIEW
// ═══════════════════════════════════════════════════════════════════════════════
//
//  ① 2× SG90 servo (gripper fingers — mirrored)
//       Left  servo: 0°  = open,  180° = closed   → pin 10
//       Right servo: 180°= open,    0° = closed    → pin 11
//       Both move together via open_gripper() / close_gripper()
//
//  ② 2× NEMA 17 extension-arm steppers (shared step pin, mirrored dirs)
//       Shared STEP pin  → pin 3
//       Left  DIR pin    → pin 2
//       Right DIR pin    → pin 4   (opposite logic to left — mirrored)
//       Home limit switch (arms retracted)  → pin 8   (INPUT_PULLUP, LOW = hit)
//       End-of-travel switch (arms extended) → pin 9   (INPUT_PULLUP, LOW = hit)
//       Driver: same TB6600 / A4988 at 8 microsteps → 1600 steps/rev
//
//  ③ 1× NEMA 23 rotation stepper (turntable)
//       STEP pin → pin 5
//       DIR  pin → pin 6
//       Home limit switch (0° position) → pin 7   (INPUT_PULLUP, LOW = hit)
//       Pick limit switch (90° pick position) → pin 8 (INPUT_PULLUP, LOW = hit)
//       Driver: TB6600 at 8 microsteps → 1600 steps/rev
//       Pick angle: 90° from home, detected by ROT_PICK_SW, not by step count
//
// ═══════════════════════════════════════════════════════════════════════════════
// HOMING SEQUENCE  (triggered by {"cmd":"home"})
// ═══════════════════════════════════════════════════════════════════════════════
//   Step 1  Open both servos  (move to open angle)
//   Step 2  Retract extension arms until HOME limit switch clicks
//   Step 3  Rotate NEMA 23 until ROTATION home switch clicks → zero set
//   → sends {"type":"home_complete","success":true}
//
// ═══════════════════════════════════════════════════════════════════════════════
// PICK SEQUENCE  (triggered by {"cmd":"pick"})
// ═══════════════════════════════════════════════════════════════════════════════
//   Step 1  Rotate NEMA 23 until ROT_PICK_SW clicks (90° pick position,
//           detected by the limit switch, not by counting steps —
//           ROT_PICK_STEPS is kept only as a safety timeout ceiling)
//   Step 2  Extend arms EXTEND_STEPS steps (or until end-of-travel switch)
//   Step 3  Close servos
//   Step 4  Retract arms back until ARM_HOME_SW clicks
//   Step 5  Rotate NEMA 23 back until ROT_HOME_SW clicks (return to zero)
//   → sends {"type":"pick_complete","success":true}
//
// ═══════════════════════════════════════════════════════════════════════════════
// SERIAL PROTOCOL — 115200 baud, newline-terminated JSON
// ═══════════════════════════════════════════════════════════════════════════════
//   Pi → Arduino:
//     {"cmd":"home"}
//     {"cmd":"pick"}
//     {"cmd":"status"}
//     {"cmd":"stop"}
//
//   Arduino → Pi:
//     {"type":"boot",          "msg":"carriage ready"}
//     {"type":"ack",           "cmd":"home"}
//     {"type":"home_complete", "success":true}
//     {"type":"ack",           "cmd":"pick"}
//     {"type":"pick_complete", "success":true}
//     {"type":"pick_complete", "success":false,"reason":"..."}
//     {"type":"status",        "state":"IDLE","homed":true,...}
//     {"type":"error",         "msg":"..."}

#include <ArduinoJson.h>
#include <Servo.h>

// ─── Pin definitions ───────────────────────────────────────────────────────────
// Gripper servos
#define SERVO_LEFT_PIN        9
#define SERVO_RIGHT_PIN       10

// Extension arm steppers (shared STEP, mirrored DIR)
#define ARM_STEP_PIN          3
#define ARM_DIR_LEFT_PIN      2
#define ARM_DIR_RIGHT_PIN     4
#define ARM_HOME_SW           6   // retracted / home position
#define ARM_END_SW            7


// Rotation NEMA 23
#define ROT_STEP_PIN          12
#define ROT_DIR_PIN           11
#define ROT_HOME_SW           13   // 0° reference position
#define ROT_PICK_SW           8    // 90° pick position (LOW = hit)

// ─── Servo angles ──────────────────────────────────────────────────────────────
// Left  servo: 0° = open,  180° = closed
// Right servo: 180° = open,  0° = closed  (mirrored)
#define SERVO_LEFT_OPEN       0
#define SERVO_LEFT_CLOSED     90
#define SERVO_RIGHT_OPEN      180
#define SERVO_RIGHT_CLOSED    90

// ─── Stepper constants ─────────────────────────────────────────────────────────
#define FULL_STEPS_PER_REV    200
#define MICROSTEPS            4
#define STEPS_PER_REV         (FULL_STEPS_PER_REV * MICROSTEPS)   // 1600

// Extension arms — configurable travel distance
// Tune EXTEND_STEPS to match your physical arm travel
#define EXTEND_STEPS          3200UL    // 2 full revolutions — adjust as needed

// Rotation NEMA 23 — 90° pick angle
// The pick position is now detected by ROT_PICK_SW (limit switch), not by
// counting steps. ROT_PICK_STEPS is retained only as a safety ceiling in case
// the switch is never reached (e.g. wiring fault) so the motor does not spin
// forever — it should be set comfortably higher than the real step count for
// 90° so it never trips before the switch under normal operation.
#define ROT_PICK_STEPS         3000UL    // safety timeout ceiling — adjust as needed

// ─── Speed constants ───────────────────────────────────────────────────────────
// Arms homing: slow retract so switch is not hit hard
#define ARM_HOME_SPEED        450UL    // steps/sec  (~0.375 rev/sec)

// Arms extend: normal working speed
#define ARM_SPEED             1200UL   // steps/sec  //was 1200

// Rotation homing: slow so home switch is caught cleanly
#define ROT_HOME_SPEED        600UL    // steps/sec

// Rotation pick move: normal working speed
#define ROT_SPEED             1200UL   // steps/sec

// ─── Pulse timing ──────────────────────────────────────────────────────────────
#define STEP_PULSE_US         5        // HIGH and LOW pulse width (µs)
#define DIR_SETUP_US          5        // DIR must be stable before STEP rises

// ─── Debug ─────────────────────────────────────────────────────────────────────
#define DEBUG_VERBOSE         false
#define STATUS_REPORT_MS      500
#define SERIAL_BAUD           115200

// ─── State machine ─────────────────────────────────────────────────────────────
enum State
{
    S_IDLE,

    // — Homing substates —
    S_HOME_SERVO_OPEN,       // open both servos
    S_HOME_ARM_RETRACT,      // retract arms until ARM_HOME_SW clicks
    S_HOME_ROT_FIND,         // spin rotation until ROT_HOME_SW clicks
    S_HOME_DONE,             // set homed flag, send result

    // — Pick substates —
    S_PICK_ROT_MOVE,         // rotate until ROT_PICK_SW clicks (90° pick position)
    S_PICK_ARM_EXTEND,       // extend arms EXTEND_STEPS steps
    S_PICK_SERVO_CLOSE,      // close gripper
    S_PICK_ARM_RETRACT,      // retract arms back until ARM_HOME_SW clicks
    S_PICK_ROT_RETURN,       // rotate back until ROT_HOME_SW clicks (return to zero)
    S_PICK_DONE,             // send pick_complete

    S_ERROR                  // fault — stop+home required to recover
};

static State         current_state   = S_IDLE;
static bool          is_homed        = false;

// Extension arm step counter (used during extend move)
static unsigned long arm_steps_done  = 0;

// Rotation step counter (used during pick rotation — safety ceiling only)
static unsigned long rot_steps_done  = 0;

// Timestamps for non-blocking step pulses
static unsigned long last_arm_step_us = 0;
static unsigned long last_rot_step_us = 0;

// Debug timer
static unsigned long status_timer     = 0;

// Servo objects
static Servo servo_left;
static Servo servo_right;

// ─── JSON helpers ──────────────────────────────────────────────────────────────
static void send_json(JsonDocument &doc)
{
    serializeJson(doc, Serial);
    Serial.println();
}

static void send_status()
{
    StaticJsonDocument<256> doc;
    doc["type"]        = "status";
    doc["state"]       = (current_state == S_IDLE)  ? "IDLE"
                       : (current_state == S_ERROR) ? "ERROR"
                       :                              "BUSY";
    doc["homed"]       = is_homed;
    doc["arm_home_sw"] = (digitalRead(ARM_HOME_SW) == LOW);
    doc["arm_end_sw"]  = (digitalRead(ARM_END_SW)  == LOW);
    doc["rot_home_sw"] = (digitalRead(ROT_HOME_SW) == LOW);
    doc["rot_pick_sw"] = (digitalRead(ROT_PICK_SW) == LOW);
    doc["busy"]        = (current_state != S_IDLE && current_state != S_ERROR);
    send_json(doc);
}

static void send_ack(const char *cmd)
{
    StaticJsonDocument<64> doc;
    doc["type"] = "ack";
    doc["cmd"]  = cmd;
    send_json(doc);
}

static void send_error(const char *msg)
{
    StaticJsonDocument<128> doc;
    doc["type"] = "error";
    doc["msg"]  = msg;
    send_json(doc);
    current_state = S_ERROR;
}

static void send_home_result(bool success, const char *reason = "")
{
    StaticJsonDocument<128> doc;
    doc["type"]    = "home_complete";
    doc["success"] = success;
    if (!success) doc["reason"] = reason;
    send_json(doc);
}

static void send_pick_result(bool success, const char *reason = "")
{
    StaticJsonDocument<128> doc;
    doc["type"]    = "pick_complete";
    doc["success"] = success;
    if (!success) doc["reason"] = reason;
    send_json(doc);
}

// ─── Servo helpers ─────────────────────────────────────────────────────────────
static void open_gripper()
{
    servo_left.write(SERVO_LEFT_OPEN);
    servo_right.write(SERVO_RIGHT_OPEN);
}

static void close_gripper()
{
    servo_left.write(SERVO_LEFT_CLOSED);
    servo_right.write(SERVO_RIGHT_CLOSED);
}

// ─── Extension arm stepper helpers ────────────────────────────────────────────
// Set direction: extend = arms go out, retract = arms come back home
static void arm_set_dir(bool extend)
{
    // Left  motor: HIGH = extend, LOW = retract
    // Right motor: mirrored — LOW = extend, HIGH = retract
    digitalWrite(ARM_DIR_LEFT_PIN,  extend ? LOW : HIGH);
    digitalWrite(ARM_DIR_RIGHT_PIN, extend ? HIGH  : LOW);
    delayMicroseconds(DIR_SETUP_US);
}

// Pulse both arm motors together (shared STEP pin)
static void arm_pulse()
{
    digitalWrite(ARM_STEP_PIN, HIGH);
    delayMicroseconds(STEP_PULSE_US);
    digitalWrite(ARM_STEP_PIN, LOW);
    delayMicroseconds(STEP_PULSE_US);
}

// Non-blocking: retract one step toward ARM_HOME_SW.
// Returns true when switch clicks (home reached).
static bool arm_step_to_home(unsigned long speed)
{
    if (digitalRead(ARM_HOME_SW) == LOW) return true;   // already home

    unsigned long now      = micros();
    unsigned long interval = 1000000UL / speed;
    if (now - last_arm_step_us < interval) return false;
    last_arm_step_us = now;

    arm_set_dir(false);   // retract
    arm_pulse();

    return (digitalRead(ARM_HOME_SW) == LOW);
}

// Non-blocking: extend one step. Watches end-of-travel switch.
// Returns true when target_steps reached.
// If end switch fires early, reports JSON and returns true (sequence continues).
static bool arm_step_extend(unsigned long target_steps, unsigned long speed)
{
    // End-of-travel switch hit — stop and report
    if (digitalRead(ARM_END_SW) == LOW)
    {
        StaticJsonDocument<128> doc;
        doc["type"]  = "arm_end_sw";
        doc["msg"]   = "extension end-of-travel switch triggered — arms stopped";
        send_json(doc);
        return true;   // treat as done, sequence continues
    }

    if (arm_steps_done >= target_steps) return true;

    unsigned long now      = micros();
    unsigned long interval = 1000000UL / speed;
    if (now - last_arm_step_us < interval) return false;
    last_arm_step_us = now;

    arm_set_dir(true);   // extend
    arm_pulse();
    arm_steps_done++;

    // Re-check switch immediately after the step
    if (digitalRead(ARM_END_SW) == LOW)
    {
        StaticJsonDocument<128> doc;
        doc["type"]  = "arm_end_sw";
        doc["msg"]   = "extension end-of-travel switch triggered — arms stopped";
        send_json(doc);
        return true;
    }

    return (arm_steps_done >= target_steps);
}

// ─── Rotation stepper helpers ──────────────────────────────────────────────────
// Set rotation direction
static void rot_set_dir(bool clockwise)
{
    digitalWrite(ROT_DIR_PIN, clockwise ? HIGH : LOW);
    delayMicroseconds(DIR_SETUP_US);
}

// Pulse the rotation motor
static void rot_pulse()
{
    digitalWrite(ROT_STEP_PIN, HIGH);
    delayMicroseconds(STEP_PULSE_US);
    digitalWrite(ROT_STEP_PIN, LOW);
    delayMicroseconds(STEP_PULSE_US);
}

// Non-blocking: spin rotation motor until ROT_HOME_SW clicks.
// Returns true when switch is hit.
static bool rot_step_to_home(unsigned long speed)
{
    if (digitalRead(ROT_HOME_SW) == LOW) return true;

    unsigned long now      = micros();
    unsigned long interval = 1000000UL / speed;
    if (now - last_rot_step_us < interval) return false;
    last_rot_step_us = now;

    rot_set_dir(false);   // counter-clockwise toward home — flip if needed
    rot_pulse();

    return (digitalRead(ROT_HOME_SW) == LOW);
}

// Non-blocking: rotate toward the pick position. The 90° pick position is
// detected by ROT_PICK_SW (limit switch) rather than by counting steps.
// target_steps is kept only as a safety timeout ceiling in case the switch (360 degree)
// is never reached, so the motor cannot spin indefinitely.
// Returns true when the pick switch is hit (or the safety ceiling is hit).
static bool rot_step_pick(unsigned long target_steps, unsigned long speed)
{
    if (digitalRead(ROT_PICK_SW) == LOW) return true;   // pick position reached

   // if (rot_steps_done >= target_steps) return true;   // safetyafety ceiling reached

    unsigned long now      = micros();
    unsigned long interval = 1000000UL / speed;
    if (now - last_rot_step_us < interval) return false;
    last_rot_step_us = now;

    rot_set_dir(true);   // clockwise toward pick position — flip if needed
    rot_pulse();
    rot_steps_done++;

    // Re-check switch immediately after the step
    if (digitalRead(ROT_PICK_SW) == LOW) return true;

    return (rot_steps_done >= target_steps);
}

// ─── Command handler ───────────────────────────────────────────────────────────
static void handle_command(const String &line)
{
    StaticJsonDocument<128> doc;
    if (deserializeJson(doc, line) != DeserializationError::Ok)
    {
        send_error("JSON parse error");
        return;
    }

    const char *cmd = doc["cmd"] | "";

    // status and stop always accepted
    if (strcmp(cmd, "status") == 0)
    {
        send_status();
        return;
    }

    if (strcmp(cmd, "stop") == 0)
    {
        current_state = S_IDLE;
        is_homed      = false;
        send_ack("stop");
        return;
    }

    // all other commands require IDLE or ERROR state
    if (current_state != S_IDLE && current_state != S_ERROR)
    {
        send_error("busy — wait for current sequence to complete");
        return;
    }

    if (strcmp(cmd, "home") == 0)
    {
        is_homed      = false;
        current_state = S_HOME_SERVO_OPEN;
        send_ack("home");
        return;
    }

    if (strcmp(cmd, "pick") == 0)
    {
        if (!is_homed)
        {
            send_error("not homed — send home command first");
            return;
        }
        rot_steps_done = 0;
        arm_steps_done = 0;
        current_state  = S_PICK_ROT_MOVE;
        send_ack("pick");
        return;
    }

    send_error("unknown command");
}

// ─── State machine ─────────────────────────────────────────────────────────────
static void run_state_machine()
{
    switch (current_state)
    {
        // ── Quiescent ────────────────────────────────────────────────────────
        case S_IDLE:
        case S_ERROR:
            break;

        // ── Homing: step 1 — open servos ─────────────────────────────────────
        case S_HOME_SERVO_OPEN:
            open_gripper();
            // Servos are slew-rate limited internally; give them time to move
            delay(500);
            arm_steps_done   = 0;
            last_arm_step_us = micros();
            current_state    = S_HOME_ARM_RETRACT;
            break;

        // ── Homing: step 2 — retract arms until ARM_HOME_SW ──────────────────
        case S_HOME_ARM_RETRACT:
            if (arm_step_to_home(ARM_HOME_SPEED))
            {
                last_rot_step_us = micros();
                current_state    = S_HOME_ROT_FIND;
            }
            break;

        // ── Homing: step 3 — spin rotation until ROT_HOME_SW ─────────────────
        case S_HOME_ROT_FIND:
            if (rot_step_to_home(ROT_HOME_SPEED))
            {
                current_state = S_HOME_DONE;
            }
            break;

        // ── Homing: complete ──────────────────────────────────────────────────
        case S_HOME_DONE:
            is_homed      = true;
            current_state = S_IDLE;
            send_home_result(true);
            break;

        // ── Pick: step 1 — rotate to pick angle (stopped by ROT_PICK_SW) ─────
        case S_PICK_ROT_MOVE:
            if (rot_step_pick(ROT_PICK_STEPS, ROT_SPEED))
            {
                arm_steps_done   = 0;
                last_arm_step_us = micros();
                current_state    = S_PICK_ARM_EXTEND;
            }
            break;

        // ── Pick: step 2 — extend arms ────────────────────────────────────────
        case S_PICK_ARM_EXTEND:
            if (arm_step_extend(EXTEND_STEPS, ARM_SPEED))
            {
                current_state = S_PICK_SERVO_CLOSE;
            }
            break;

        // ── Pick: step 3 — close gripper ─────────────────────────────────────
        case S_PICK_SERVO_CLOSE:
            close_gripper();
            delay(500);   // allow SG90 to reach closed position
            last_arm_step_us = micros();
            current_state    = S_PICK_ARM_RETRACT;
            break;

        // ── Pick: step 4 — retract arms back until ARM_HOME_SW ───────────────
        case S_PICK_ARM_RETRACT:
            if (arm_step_to_home(ARM_HOME_SPEED))
            {
                last_rot_step_us = micros();
                current_state    = S_PICK_ROT_RETURN;
            }
            break;

        // ── Pick: step 5 — rotate back to zero until ROT_HOME_SW ─────────────
        case S_PICK_ROT_RETURN:
            if (rot_step_to_home(ROT_HOME_SPEED))
            {
                current_state = S_PICK_DONE;
            }
            break;

        // ── Pick: complete ────────────────────────────────────────────────────
        case S_PICK_DONE:
            current_state = S_IDLE;
            send_pick_result(true);
            break;
    }
}

// ─── setup ────────────────────────────────────────────────────────────────────
void setup()
{
    Serial.begin(SERIAL_BAUD);

    // Servo attach
    servo_left.attach(SERVO_LEFT_PIN);
    servo_right.attach(SERVO_RIGHT_PIN);
    open_gripper();   // start open

    // Extension arm stepper pins
    pinMode(ARM_STEP_PIN,       OUTPUT);
    pinMode(ARM_DIR_LEFT_PIN,   OUTPUT);
    pinMode(ARM_DIR_RIGHT_PIN,  OUTPUT);
    digitalWrite(ARM_STEP_PIN,      LOW);
    digitalWrite(ARM_DIR_LEFT_PIN,  LOW);
    digitalWrite(ARM_DIR_RIGHT_PIN, HIGH);

    // Rotation stepper pins
    pinMode(ROT_STEP_PIN, OUTPUT);
    pinMode(ROT_DIR_PIN,  OUTPUT);
    digitalWrite(ROT_STEP_PIN, LOW);
    digitalWrite(ROT_DIR_PIN,  LOW);

    // Limit switches
    pinMode(ARM_HOME_SW, INPUT_PULLUP);
    pinMode(ARM_END_SW,  INPUT_PULLUP);
    pinMode(ROT_HOME_SW, INPUT_PULLUP);
    pinMode(ROT_PICK_SW, INPUT_PULLUP);

    StaticJsonDocument<64> boot;
    boot["type"] = "boot";
    boot["msg"]  = "carriage ready";
    send_json(boot);
}

// ─── loop ─────────────────────────────────────────────────────────────────────
void loop()
{
    if (Serial.available())
    {
        String line = Serial.readStringUntil('\n');
        line.trim();
        if (line.length() > 0)
            handle_command(line);
    }

    run_state_machine();

    if (DEBUG_VERBOSE)
    {
        unsigned long now = millis();
        if (now - status_timer >= STATUS_REPORT_MS)
        {
            status_timer = now;
            send_status();
        }
    }
}

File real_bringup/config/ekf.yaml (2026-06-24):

### robot_localization EKF node config
### Fuses wheel odometry (/odom) + IMU (/imu/data)
### output: /odometry/filtered, used by Nav2

ekf_filter_node:
  ros__parameters:

    frequency: 30.0          # Hz,how often EKF publishes
    sensor_timeout: 0.1      # if no sensor update for 0.1 sec, ignore that sensor
    two_d_mode: true         # we're a ground robot -> ignore Z, roll, pitch
    publish_tf: true         # publishes odom -> base_link (CHASSIS) TF
    publish_acceleration: false

    # Frame definitions
    map_frame:      map
    odom_frame:     odom
    base_link_frame: CHASSIS   
    world_frame:    odom       # EKF works in odom frame (not map)

    #Odometry comes from ESP32 encoder calculations
    odom0: /odom
    # What to fuse from /odom:
    # [x,  y,  z,
    #  roll, pitch, yaw,
    #  vx,  vy,  vz,
    #  vroll, vpitch, vyaw,
    #  ax,  ay,  az]
    odom0_config: [true,  true,  false,
                   false, false, false,
                   true,  false, false,
                   false, false, true,
                   false, false, false]
    odom0_differential: false   #Is this sensor giving CHANGE(true) or ABSOLUTE value(false)?
    odom0_relative: false       #Is data relative to starting point?(false) or does it drift over time(true)?
    odom0_queue_size: 10        # store last 10 messages

    # IMU from ESP32 MPU-6050
    imu0: /imu/data
    # Fuse only yaw rate (gyro) (how fast the robot rotates) from IMU (most reliable part of MPU-6050)
    imu0_config: [false, false, false,
                  false, false, false,
                  false, false, false,
                  false, false, true,
                  false, false, false]
    imu0_differential: false
    imu0_relative: true        # MPU-6050 has no absolute heading reference(yaw drifts over time)( treat as relative)
    imu0_queue_size: 10
    imu0_remove_gravitational_acceleration: false  #removes gravity from linear acceleration data (not needed since we're not fusing linear accel)

    # Process noise covariance — how much we trust the model vs sensors
    # Increase a value → trust sensors more for that state
    process_noise_covariance: [0.05, 0.0, 0.0, 0.0, 0.0, 0.0, 0.0, 0.0, 0.0, 0.0, 0.0, 0.0, 0.0, 0.0, 0.0, 0.0, 0.05, 0.0, 0.0, 0.0, 0.0, 0.0, 0.0, 0.0, 0.0, 0.0, 0.0, 0.0, 0.0, 0.0, 0.0, 0.0, 0.06, 0.0, 0.0, 0.0, 0.0, 0.0, 0.0, 0.0, 0.0, 0.0, 0.0, 0.0, 0.0, 0.0, 0.0, 0.0, 0.03, 0.0, 0.0, 0.0, 0.0, 0.0, 0.0, 0.0, 0.0, 0.0, 0.0, 0.0, 0.0, 0.0, 0.0, 0.0, 0.03, 0.0, 0.0, 0.0, 0.0, 0.0, 0.0, 0.0, 0.0, 0.0, 0.0, 0.0, 0.0, 0.0, 0.0, 0.0, 0.06, 0.0, 0.0, 0.0, 0.0, 0.0, 0.0, 0.0, 0.0, 0.0, 0.0, 0.0, 0.0, 0.0, 0.0, 0.0, 0.025, 0.0, 0.0, 0.0, 0.0, 0.0, 0.0, 0.0, 0.0, 0.0, 0.0, 0.0, 0.0, 0.0, 0.0, 0.0, 0.025, 0.0, 0.0, 0.0, 0.0, 0.0, 0.0, 0.0, 0.0, 0.0, 0.0, 0.0, 0.0, 0.0, 0.0, 0.0, 0.04, 0.0, 0.0, 0.0, 0.0, 0.0, 0.0, 0.0, 0.0, 0.0, 0.0, 0.0, 0.0, 0.0, 0.0, 0.0, 0.01, 0.0, 0.0, 0.0, 0.0, 0.0, 0.0, 0.0, 0.0, 0.0, 0.0, 0.0, 0.0, 0.0, 0.0, 0.0, 0.01, 0.0, 0.0, 0.0, 0.0, 0.0, 0.0, 0.0, 0.0, 0.0, 0.0, 0.0, 0.0, 0.0, 0.0, 0.0, 0.02, 0.0, 0.0, 0.0, 0.0, 0.0, 0.0, 0.0, 0.0, 0.0, 0.0, 0.0, 0.0, 0.0, 0.0, 0.0, 0.01, 0.0, 0.0, 0.0, 0.0, 0.0, 0.0, 0.0, 0.0, 0.0, 0.0, 0.0, 0.0, 0.0, 0.0, 0.0, 0.01, 0.0, 0.0, 0.0, 0.0, 0.0, 0.0, 0.0, 0.0, 0.0, 0.0, 0.0, 0.0, 0.0, 0.0, 0.0, 0.015]

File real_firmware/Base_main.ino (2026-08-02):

#include <ArduinoJson.h>

// ===================== BTS7960 motor driver pins =====================
#define L_RPWM  15
#define L_LPWM   4
#define L_R_EN  27
#define L_L_EN  14

#define R_RPWM  32
#define R_LPWM  33
#define R_R_EN  25
#define R_L_EN  26

// ===================== LEDC PWM config =====================
// 20kHz keeps switching noise above the audible range and gives BTS7960
// cleaner switching than the ~1kHz default analogWrite() emulation on ESP32.
#define PWM_FREQ_HZ   20000
#define PWM_RES_BITS  8      // 0-255 duty range, matches rest of the code

// ===================== Open-loop tuning (46 RPM motor) =====================
// A 46 RPM gear motor has a high reduction ratio -> real gearbox stiction.
// Below MIN_MOVING_PWM the motor just buzzes/stalls instead of turning.
// MEASURE THIS: slowly ramp PWM from 0 with wheels off the ground / under
// light load and note the duty at which the wheel first starts turning
// smoothly. Start with this guess and adjust.
#define MIN_MOVING_PWM   70     // tune per-motor, ~27% duty as a starting point
#define MAX_PWM          255
#define OPEN_LOOP_MAX_MS 0.313f  // must match MAX_LINEAR on the ROS side

// Slew limiting: max PWM change per control step, prevents instant jumps
// from feeling like "cuts" in motion.
#define SLEW_STEP_PER_TICK   8      // PWM counts per control tick
#define CONTROL_PERIOD_MS    20     // slew + motor update period

// Command watchdog: if no valid JSON arrives in this window, stop motors.
#define CMD_TIMEOUT_MS  300

float left_wheel_target_ms  = 0.0f;
float right_wheel_target_ms = 0.0f;

int left_pwm_current  = 0;   // signed, current slewed PWM actually applied
int right_pwm_current = 0;

unsigned long last_cmd_millis   = 0;
unsigned long last_control_tick = 0;

// ===================== Motor output =====================
void setLeftMotor(int signed_pwm) {
    int mag = constrain(abs(signed_pwm), 0, MAX_PWM);
    if (signed_pwm >= 0) {
        ledcWrite(L_RPWM, mag);
        ledcWrite(L_LPWM, 0);
    } else {
        ledcWrite(L_RPWM, 0);
        ledcWrite(L_LPWM, mag);
    }
}

void setRightMotor(int signed_pwm) {
    int mag = constrain(abs(signed_pwm), 0, MAX_PWM);
    if (signed_pwm >= 0) {
        ledcWrite(R_RPWM, mag);
        ledcWrite(R_LPWM, 0);
    } else {
        ledcWrite(R_RPWM, 0);
        ledcWrite(R_LPWM, mag);
    }
}

// Map target velocity (m/s, signed) -> signed target PWM with a minimum
// moving floor, so any nonzero command is guaranteed to actually turn the
// wheel instead of sitting below stiction.
int velocityToTargetPwm(float v_ms) {
    if (fabsf(v_ms) < 1e-3f) return 0;
    float mag_ms = fminf(fabsf(v_ms), OPEN_LOOP_MAX_MS);
    int mag_pwm = MIN_MOVING_PWM +
                  (int)(mag_ms * (MAX_PWM - MIN_MOVING_PWM) / OPEN_LOOP_MAX_MS);
    mag_pwm = constrain(mag_pwm, 0, MAX_PWM);
    return (v_ms < 0.0f) ? -mag_pwm : mag_pwm;
}

int applySlew(int current, int target, int max_step) {
    if (target > current) return min(target, current + max_step);
    if (target < current) return max(target, current - max_step);
    return current;
}

// ===================== Non-blocking serial parse =====================
// Accumulates characters as they arrive instead of blocking on
// readBytesUntil(), which could stall the loop for up to Serial's timeout
// if a line arrives split across reads.
void parseSerialCommand() {
    static char buf[128];
    static uint8_t idx = 0;

    while (Serial.available()) {
        char c = Serial.read();

        if (c == '\n') {
            buf[idx] = '\0';
            idx = 0;

            if (strlen(buf) == 0) continue;

            StaticJsonDocument<128> json_doc;
            if (deserializeJson(json_doc, buf) != DeserializationError::Ok) continue;

            if (json_doc.containsKey("left_target"))
                left_wheel_target_ms = json_doc["left_target"].as<float>();
            if (json_doc.containsKey("right_target"))
                right_wheel_target_ms = json_doc["right_target"].as<float>();

            last_cmd_millis = millis();

            // Echo back so you can confirm the board received it
            Serial.print("{\"left_target\":");
            Serial.print(left_wheel_target_ms, 4);
            Serial.print(",\"right_target\":");
            Serial.print(right_wheel_target_ms, 4);
            Serial.println("}");

        } else if (idx < sizeof(buf) - 1) {
            buf[idx++] = c;
        }
        // if the line is longer than the buffer, extra chars are dropped
        // until '\n' resets idx — prevents buffer overrun on garbage input
    }
}

// ===================== Control loop: watchdog + slew + output =====================
void updateMotors() {
    unsigned long now = millis();
    if (now - last_control_tick < CONTROL_PERIOD_MS) return;
    last_control_tick = now;

    // Watchdog: no fresh command recently -> force stop targets
    float left_cmd_ms  = left_wheel_target_ms;
    float right_cmd_ms = right_wheel_target_ms;
    if (now - last_cmd_millis > CMD_TIMEOUT_MS) {
        left_cmd_ms  = 0.0f;
        right_cmd_ms = 0.0f;
    }

    int left_target_pwm  = velocityToTargetPwm(left_cmd_ms);
    int right_target_pwm = velocityToTargetPwm(right_cmd_ms);

    left_pwm_current  = applySlew(left_pwm_current,  left_target_pwm,  SLEW_STEP_PER_TICK);
    right_pwm_current = applySlew(right_pwm_current, right_target_pwm, SLEW_STEP_PER_TICK);

    setLeftMotor(left_pwm_current);
    setRightMotor(right_pwm_current);
}

void setup() {
    Serial.begin(115200);

    pinMode(L_R_EN, OUTPUT); digitalWrite(L_R_EN, HIGH);
    pinMode(L_L_EN, OUTPUT); digitalWrite(L_L_EN, HIGH);
    pinMode(R_R_EN, OUTPUT); digitalWrite(R_R_EN, HIGH);
    pinMode(R_L_EN, OUTPUT); digitalWrite(R_L_EN, HIGH);

    ledcAttach(L_RPWM, PWM_FREQ_HZ, PWM_RES_BITS);
    ledcAttach(L_LPWM, PWM_FREQ_HZ, PWM_RES_BITS);
    ledcAttach(R_RPWM, PWM_FREQ_HZ, PWM_RES_BITS);
    ledcAttach(R_LPWM, PWM_FREQ_HZ, PWM_RES_BITS);

    last_cmd_millis   = millis();
    last_control_tick = millis();

    Serial.println("{\"info\":\"firmware ready - open loop, deadband+slew\"}");
}

void loop() {
    parseSerialCommand();
    updateMotors();
}

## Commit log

2026-05-04 Initial commit: real_description, real_bringup, real_firmware
    [CHASSIS.STL, FRONT_ROLLING.STL, FRONT_SWIVEL.STL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]
2026-05-04 Clean repo
    [CHASSIS.STL, FRONT_ROLLING.STL, FRONT_SWIVEL.STL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]
2026-05-13 deleted files
    [CHASSIS.STL, FRONT_ROLLING.STL, FRONT_SWIVEL.STL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]
2026-05-17 removed micro-ros
    [Robot_Final.urdf, controllers.yaml]
2026-05-28 removing ros2_control
    [Robot_Final.urdf, controllers.yaml]
2026-06-24 Initial commit for lifting and carriage
2026-07-01 adding carriage node
